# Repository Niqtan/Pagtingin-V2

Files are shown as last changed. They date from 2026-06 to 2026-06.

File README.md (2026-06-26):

# Pagtingin (Obstacle Detecting Glasses) 2.0

## Project Aims

The Pagtingin obstacle detecting glasses aims to help visually impaired people to easily detect obstacles in front of them through innovative glasses. While traditional walking sticks indeed help in detecting obstacles on the ground, they often fail to identify objects at chest or head level, such as low-hanging branches, open cabinets, or protruding signs. 

Hence, Pagtingin aims to aid this limitation and ensure a safe journey of navigation. Whether indoors or outdoors, the device will be able to identify potential hazards through a Time-of-Flight sensor and send real-time audio feedback, which helps users to be much more confident and safe in the user's day-to-day lives.

Pagtingin 2.0 uses a modular approach instead of a tightly coupled design, making the system easier to iterate on and refine over time. Some design changes and iterations also have been made.

## Zine
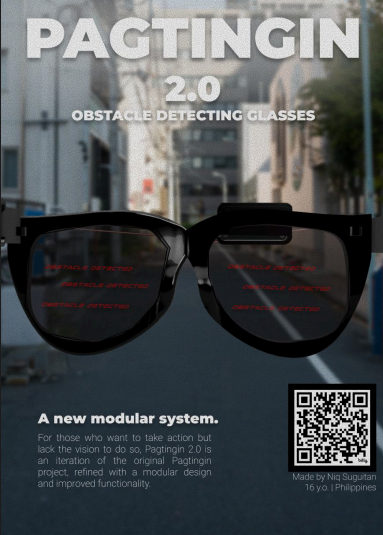
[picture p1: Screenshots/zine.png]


## Prototype Concept
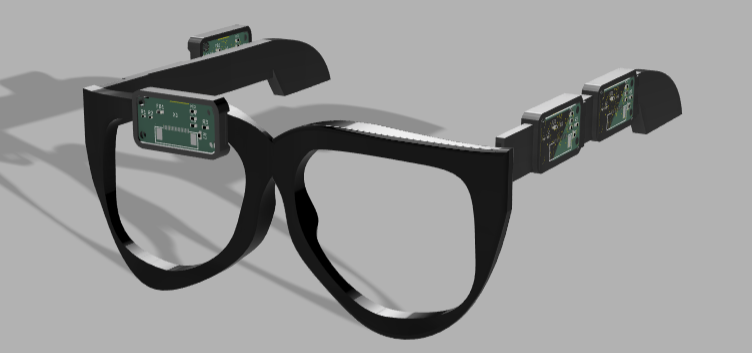
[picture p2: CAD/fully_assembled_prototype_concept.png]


## PCB 

### Main Module

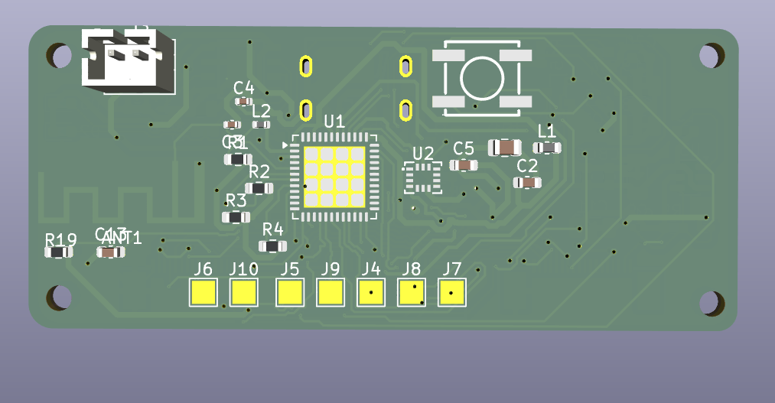
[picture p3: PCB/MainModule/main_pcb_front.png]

Image 1. Main PCB Module Front View

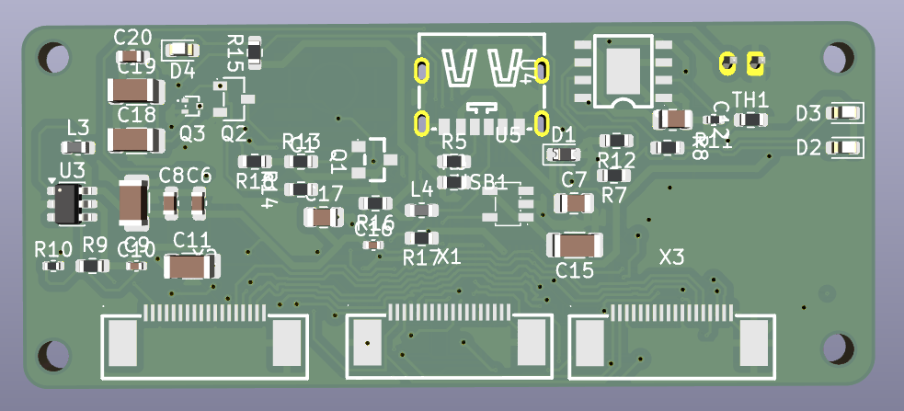
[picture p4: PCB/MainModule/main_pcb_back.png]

Image 2. Main PCB Module Backk View

### Audio Module
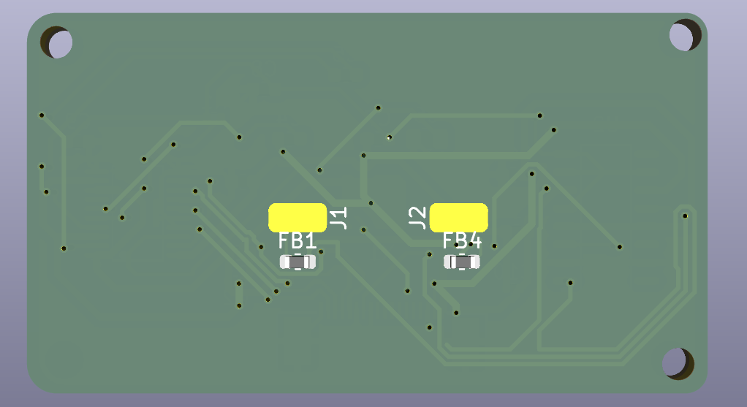
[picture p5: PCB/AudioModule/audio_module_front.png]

Image 3. Audio PCB Module Front View

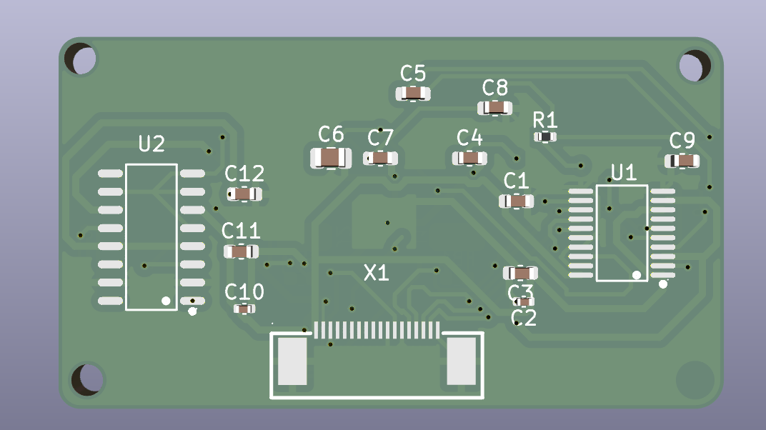
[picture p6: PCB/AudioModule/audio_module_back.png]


Image 4. Audio PCB Module Back View

### Sensor Module

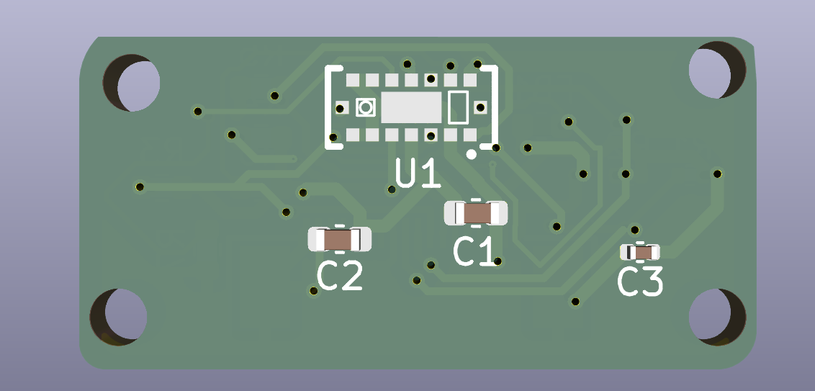
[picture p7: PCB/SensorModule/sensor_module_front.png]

Image 5. Sensor PCB Module Front View

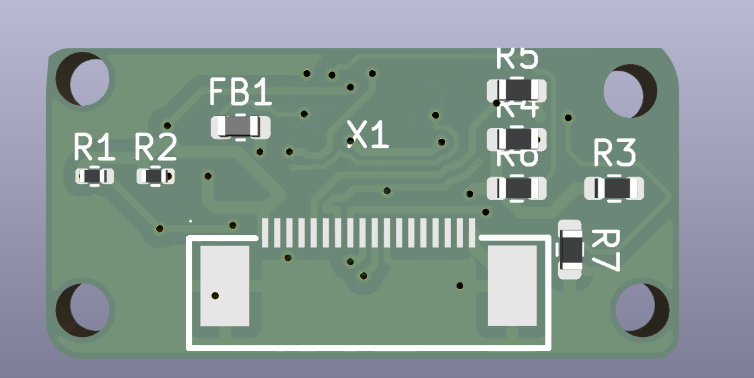
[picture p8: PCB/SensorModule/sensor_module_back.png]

Image 6. Sensor PCB Module Back View

## CAD

### Glasses Frame (with new hinges)

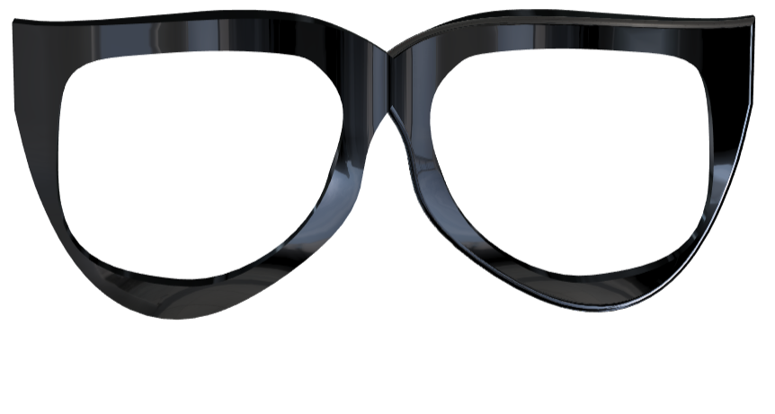
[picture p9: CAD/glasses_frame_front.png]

Image 7. Glasses Frame Front View

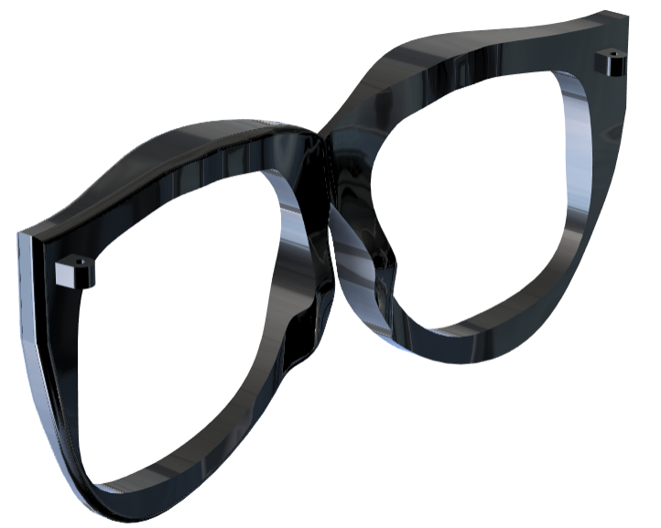
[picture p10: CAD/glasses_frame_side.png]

Image 8. Glasses Side View

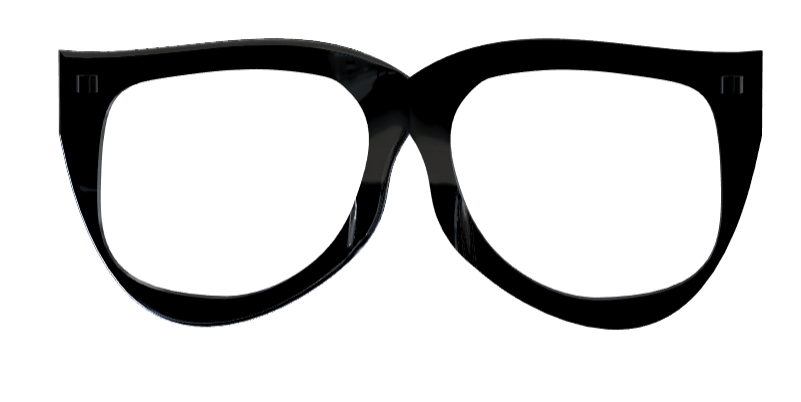
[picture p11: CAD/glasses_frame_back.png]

Image 9. Glasses Frame Back View

### Temples

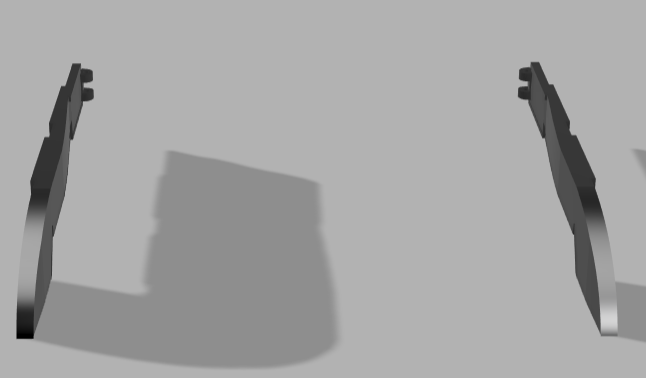
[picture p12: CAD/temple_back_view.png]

Image 10. Glasses Temple Back View

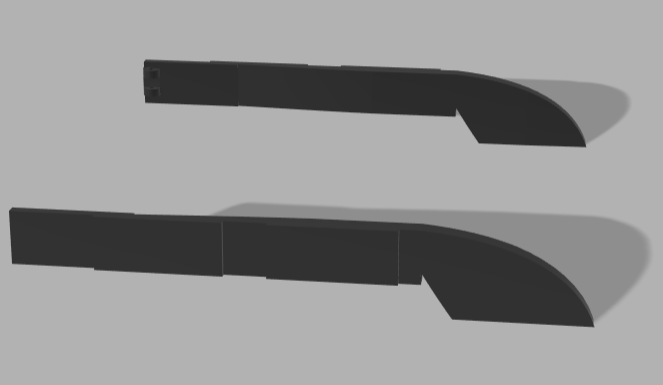
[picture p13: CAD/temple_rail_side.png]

Image 11. Glasses Rail Side View

### Module Pod
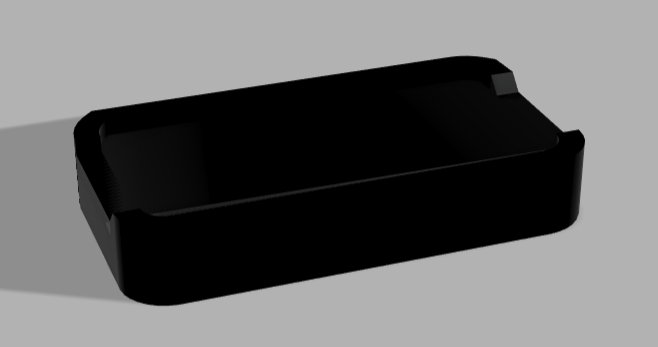
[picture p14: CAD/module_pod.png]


## 3D Printing
In terms of 3D printing, it might be better to print this in resin since the glasses frame will require precise dimensions. You may be able to print this in FDM, but it is recommended for the parameters to be as precise as possible.

## BOM

### BOM
[Bill of Materials](BOM.csv)

## Firmware
Still in progress. You may see previous prototypes in the folder for previous version's firmware. But for the firmware, I am planning to use the ESP-IDF in programming it. I chose the ESP-IDF because it allows full control over the ESP32-PICO-D4's peripherals and such. (also because I wanna challenge myself)

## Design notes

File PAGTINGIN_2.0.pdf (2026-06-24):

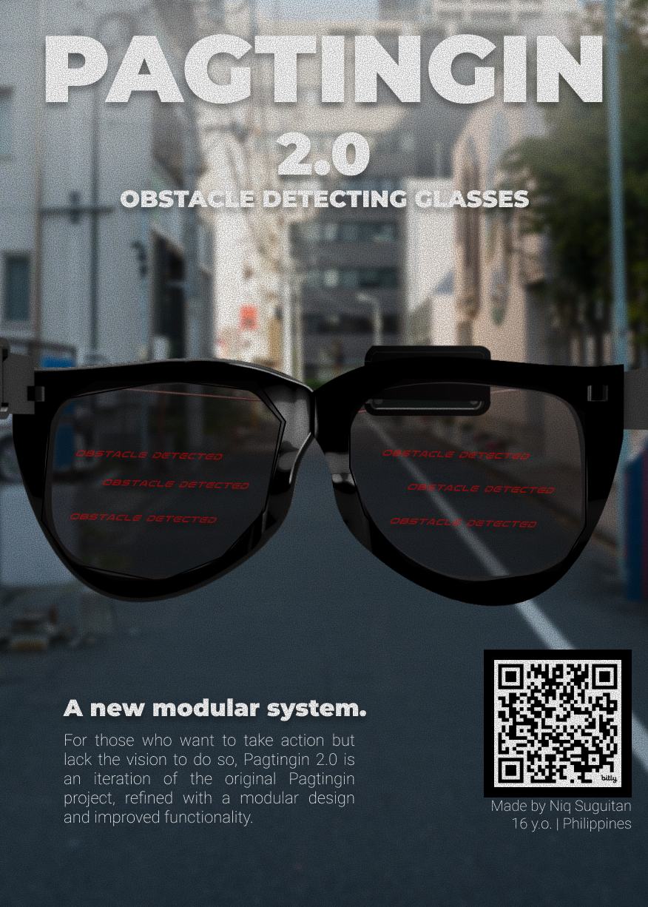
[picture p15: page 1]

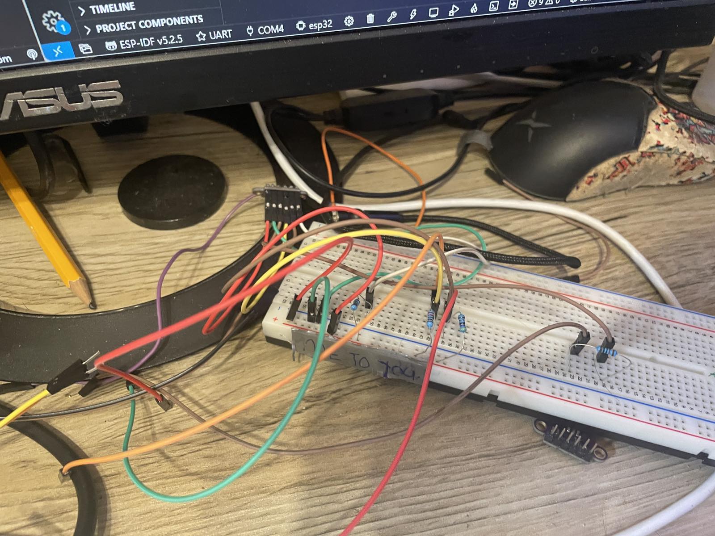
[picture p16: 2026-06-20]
Screenshots/viber_image_2025-06-27_18-02-09-457.jpg

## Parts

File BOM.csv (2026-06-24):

Comment | Quantity | Value | Footprint | LCSC Part Number | JLCPCB Component Type | Unit Price ($) | Total Price ($)
ANT1 | 1 | PCB ANTENNA 2.4GHz | RF_Antenna:Texas_SWRA117D_2.4GHz_Right |  | Extended | 0 | 0
C1,C7,C12,C17,C27 | 5 | 10µF | Capacitor_SMD:C_0805_2012Metric | C15850 | Basic | 0.0145 | 0.0725
C2,C13,C23,C31,C34 | 5 | 0.1µF | Capacitor_SMD:C_0603_1608Metric | C14663 | Basic | 0.0078 | 0.039
C3,C4,C10,C16,C24,C32,C35 | 7 | Various RF Caps (1.2p - 22p) | Capacitor_SMD:C_0402_1005Metric | C1525 | Basic | 0.0055 | 0.0385
C5,C6,C8,C22,C25,C26,C28,C29,C30,C33,C36,C37 | 12 | 1µF | Capacitor_SMD:C_0603_1608Metric | C15849 | Basic | 0.0084 | 0.1008
C9,C11,C15,C18,C19 | 5 | 22µF | Capacitor_SMD:C_1206_3216Metric | C12881 | Basic | 0.0365 | 0.1825
C20 | 1 | 4.7µF | Capacitor_SMD:C_0603_1608Metric | C19666 | Basic | 0.021 | 0.021
D1 | 1 | PTVS17VS1UR,115 | Diode_SMD:D_0603_1608Metric | C85414 | Basic | 0.046 | 0.046
D2,D4 | 2 | XL-1608PGC-06 | LED_SMD:LED_0603_1608Metric | C965863 | Basic | 0.026 | 0.052
D3 | 1 | XL-1608VRC-06 | LED_SMD:LED_0603_1608Metric | C84256 | Basic | 0.0195 | 0.0195
FB1,FB4,FB5 | 3 | MAF1608FAD151CT000 | Inductor_SMD:L_0603_1608Metric | C1033 | Basic | 0.0135 | 0.0405
J1,J2 | 2 | ESP-PROG Headers | Custom Pin Headers | C124313 | Extended | 0.115 | 0.23
J3 | 1 | USE-702528-500PCBJST | Connector_JST:JST_PH_B2B-PH-K_1x02_P2.00mm_Vertical | C131337 | Extended | 0.255 | 0.255
J4 to J12 | 9 | TestPoint / Wire Pads | TestPoint:TestPoint_Pad_2.0x2.0mm |  | Basic | 0 | 0
L1,L3,L4 | 3 | Power Inductors (2.2µ - 10µ) | Inductor_SMD:L_0603_1608Metric | C168316 | Basic | 0.068 | 0.204
L2 | 1 | 1.8nH | Inductor_SMD:L_0402_1005Metric | C148419 | Basic | 0.026 | 0.026
Q1 | 1 | AO3401A | SOT-23 | C15127 | Basic | 0.045 | 0.045
Q2 | 1 | MMBT2907ALT1G | SOT-23-3 | C40752 | Basic | 0.032 | 0.032
Q3 | 1 | MMBT2222AM3T5G | SOT-723-3 | C896289 | Basic | 0.035 | 0.035
R1,R2,R3,R4,R12,R19,R26 | 7 | 10kΩ | Resistor_SMD:R_0603_1608Metric | C25804 | Basic | 0.0032 | 0.0224
R5,R6 | 2 | 56KΩ | Resistor_SMD:R_0603_1608Metric | C23204 | Basic | 0.0032 | 0.0064
R7,R8,R20 | 3 | 1kΩ | Resistor_SMD:R_0603_1608Metric | C21190 | Basic | 0.0032 | 0.0096
R9,R28,R29,R30,R31 | 5 | 47kΩ | Resistor_SMD:R_0603_1608Metric | C25741 | Basic | 0.0032 | 0.016
R10 | 1 | 4k7Ω | Resistor_SMD:R_0402_1005Metric | C25900 | Basic | 0.0038 | 0.0038
R11,R27,R32 | 3 | 2kΩ / 2k2Ω | Resistor_SMD:R_0402_1005Metric | C25890 | Basic | 0.0038 | 0.0114
R13,R14,R18 | 3 | 10KΩ | Resistor_SMD:R_0603_1608Metric | C25804 | Basic | 0.0032 | 0.0096
R15 | 1 | 100kΩ | Resistor_SMD:R_0603_1608Metric | C25814 | Basic | 0.0032 | 0.0032
R16 | 1 | 360kΩ | Resistor_SMD:R_0603_1608Metric | C120761 | Basic | 0.0042 | 0.0042
R17 | 1 | 80.6kΩ | Resistor_SMD:R_0603_1608Metric | C121287 | Basic | 0.0042 | 0.0042
SW1 | 1 | KSC441JST2LFS | KEY-SMD_4P | C221750 | Basic | 0.213 | 0.213
TH1 | 1 | NCU18XH103F6SRB | Resistor_SMD:R_0603_1608Metric | C162670 | Basic | 0.075 | 0.075
U1 | 1 | ESP32-PICO-D4 | QFN-48-1EP_7x7mm_P0.5mm | C193707 | Extended | 4.1816 | 4.1816
U2 | 1 | BMI270 | LGA-14_L3.0-W2.5-P0.50 | C2836813 | Extended | 4.1911 | 4.1911
U3 | 1 | TLV61070ADBV | Package_TO_SOT_SMD:SOT-23-6 | C6881375 | Basic | 0.284 | 0.284
U4 | 1 | TP4056 | ESOP-8 | C16581 | Basic | 0.114 | 0.114
U5 | 1 | RT8059GJ5 | SOT-23-5 | C20542 | Basic | 0.142 | 0.142
U6 | 1 | PCM5102 | TSSOP-20_L6.5-W4.4-P0.65-LS6.4-BL | C107671 | Extended | 1.98 | 1.98
U7 | 1 | PAM8403DR | SOP-16 | C5122557 | Extended | 0.221 | 0.221
U8 | 1 | VL53L5CXV0GC_1 | LGA-16 | C3178303 | Extended | 7.4367 | 7.4367
USB1 | 1 | TYPE-C 6P | TYPE-C-SMD_TYPE-C-6P_1 | C456012 | Basic | 0.091 | 0.091
X1,X2,X3,X4,X5 | 5 | AFC07-S18FCA-00 | FPC-SMD_AFC07-S18FCA-00 | C262564 | Extended | 0.162 | 0.81
Total |  |  |  |  |  |  | 21.2695

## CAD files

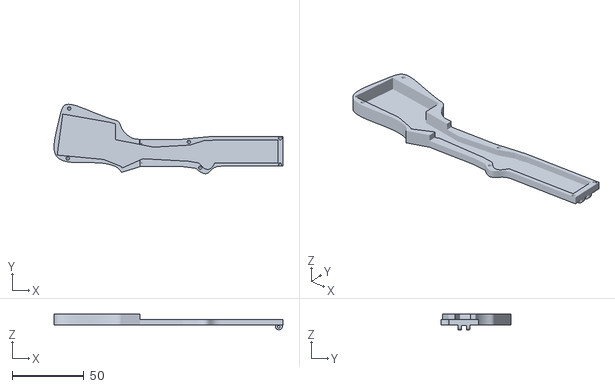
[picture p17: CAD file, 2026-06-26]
CAD/Temples Hinges.stl
159.5 x 48.4 x 10.8

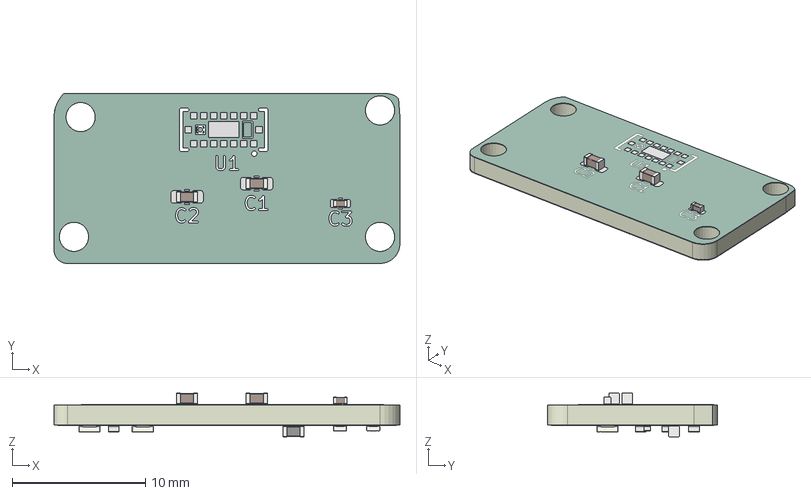
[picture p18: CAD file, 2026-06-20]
PCB/SensorModule/sensor_module.step
26.0 x 12.8 x 3.28 mm
C_0603_1608Metric x 2
C_0402_1005Metric
L_0603_1608Metric
R_0603_1608Metric x 5
R_0402_1005Metric x 2
Pagtingin_V2_Sensor_copper
Pagtingin_V2_Sensor_pad
Pagtingin_V2_Sensor_via
Pagtingin_V2_Sensor_silkscreen x 2
Pagtingin_V2_Sensor_soldermask x 2
Pagtingin_V2_Sensor_PCB

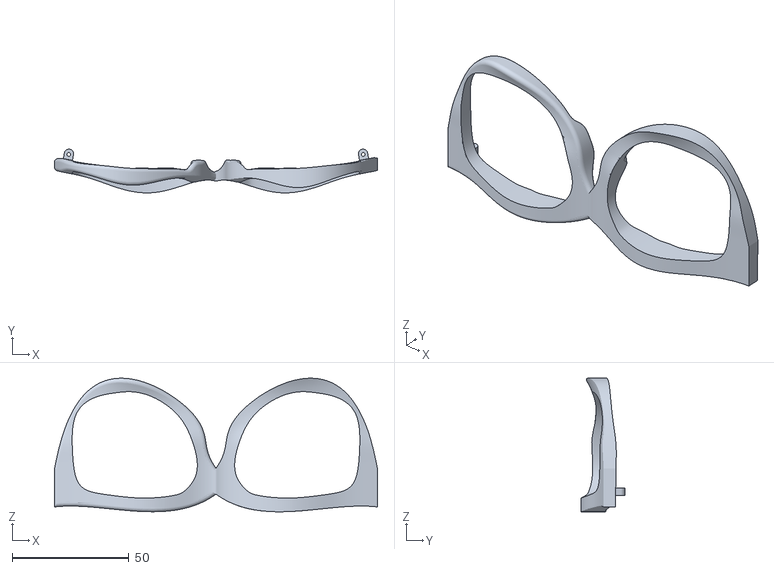
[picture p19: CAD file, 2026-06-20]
CAD/Glasses_Frame_With_Hinges.stl
138.6 x 18.8 x 57.3

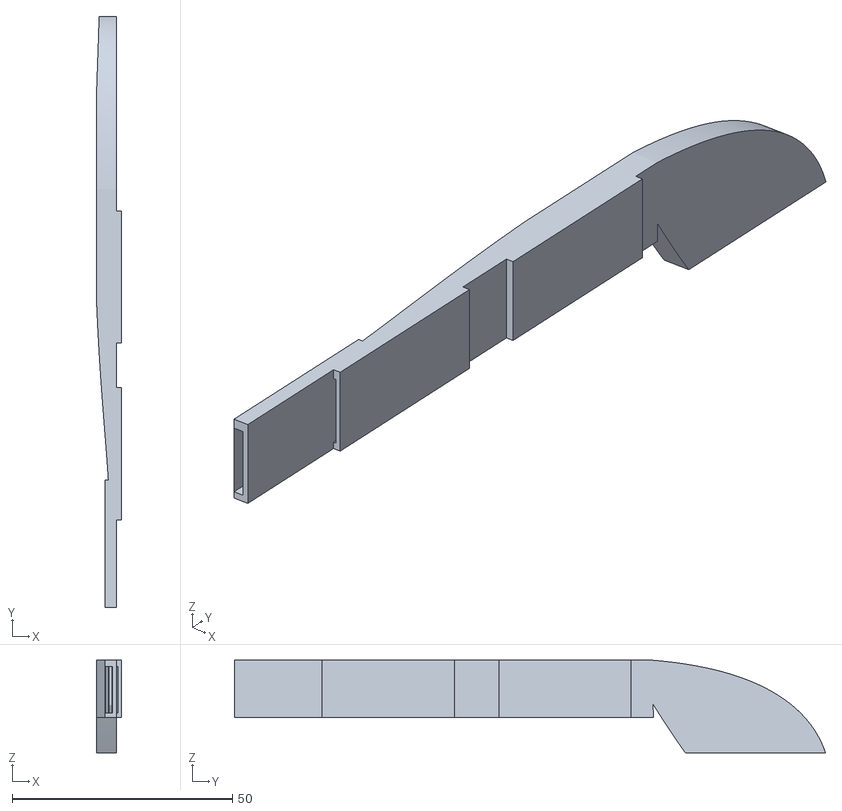
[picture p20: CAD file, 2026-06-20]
CAD/Left Temple.stl
5.70 x 134.1 x 21.0

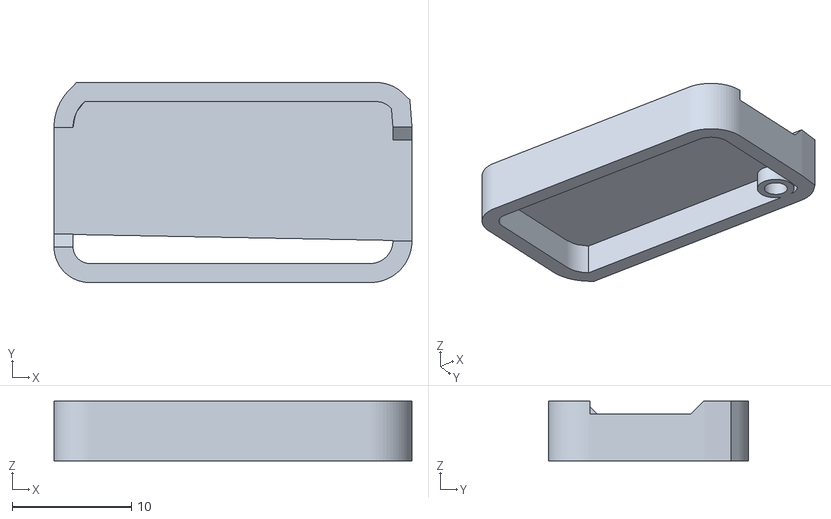
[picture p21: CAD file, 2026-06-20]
CAD/Pod.stl
30.0 x 16.8 x 5.00

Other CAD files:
CAD/Right Temple.stl
CAD/Glasses_Temples_with_hinges.f3z
CAD/Sensor_Module_Pod.f3d

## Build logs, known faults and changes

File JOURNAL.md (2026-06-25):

---
title: "Pagtingin V2"
author: "Niq Suguitan"
description: "A vision without action is called a daydream; but then again, action without a vision is called a nightmare."
created_at: "2026-05-21"
---

| Date started: May 21, 2026

# Pagtingin V2
Okay. I think it is time to start working on this project again. It's been literally almost a year since I've touched this project and all I can say is that I've changed a lot in those years. Now, we're back in Summer 2026 to work on this.

I guess to start, I would like myself to check up on why I gave up on this in the first place
- Clearly, it failed because I switched the positions of the pins of the MCU. So technically, I was quite literally trying to make it work but I had swapped the footprint pins to connect to different signals that weren't actuallly  the right footprint pins in thea actual footprint. Okay, so to explain on it much simpler, I switched each pins of the footprints to make routing easier. however, in the adctual footprint, no pins are switched, making the signals i've connected not corresponding to the actual footprint.

So that is definitely one problem, I would say.

Here's the complete list of problems that I noticed while making the PCB

1. Both PCBs were INCREDIBLY messy as hell. There were so many wires going through each of them, and it just didnt look good.
2. How the hell do you even program an ESP chip? This were mainly one of the main reasons why everything became messy
3. Some things weren't available when I asked JLCPCB to  solder all of the parts in the PCB. Also yeah, my soldering was js plain messy
4. Didn't account for some measurement of the 3d print
5. 3d printed glasses' hinges didn't work
6. And of course, the ESP32's footprint layout was wrong.

Clearly, there were so many problems here because I was so rushed into making this for Highway. But worry not, I'll try to fix them this summer.

## First Problem: How to program the ESP32-PICO-D4
I guess the first thing I can start working on is how would you even try programming the ESP32-PICO-D4 if its just a sole chip?

To program it you would need to use a USB-TO-UART bridge and programming it via the Arduino IDE.

I guess also one of the main reasons why we couldnt program the ESP32-PICO-D4 was that the pogo pins didn't fit the holes.
- This was also to me messing with the footprint's sizes.

So apparently the ESP32-PICO-D4 uses a UART bootloader mode in which it allows for firmware to be flashed over the serial communication protocol, UART.
- For this project, I think we can keep the FT2232HL-Based flashing

## Second Problem: How to know if the power delivery is working?
We test with the current version and see with a multimeter tester if the power delivery is indeed working as intended.

## Third problem: 3D Printed Hinges
The temples were okay and the PCB was able to fit but the problem was that the hinges didn't quite connect with each other.

We would probably need to add little tweaks to the 3D print and most likely try to see if it shall work.

I'll research on the META glasses how did they fit PCBs in their frames.

Going through the teardown of the meta rayban glasses, I noticed that they use a lot of flex PCBs. Flex PCBs, frankly, are quite a foreign term for me.
But as I understand, they are more of like

Quick notes:
- All the frames and the arms are made of plastic (NOT 3D PRINTED)
- Flex PCBs are more of used to houses the sensors such as proximity and light

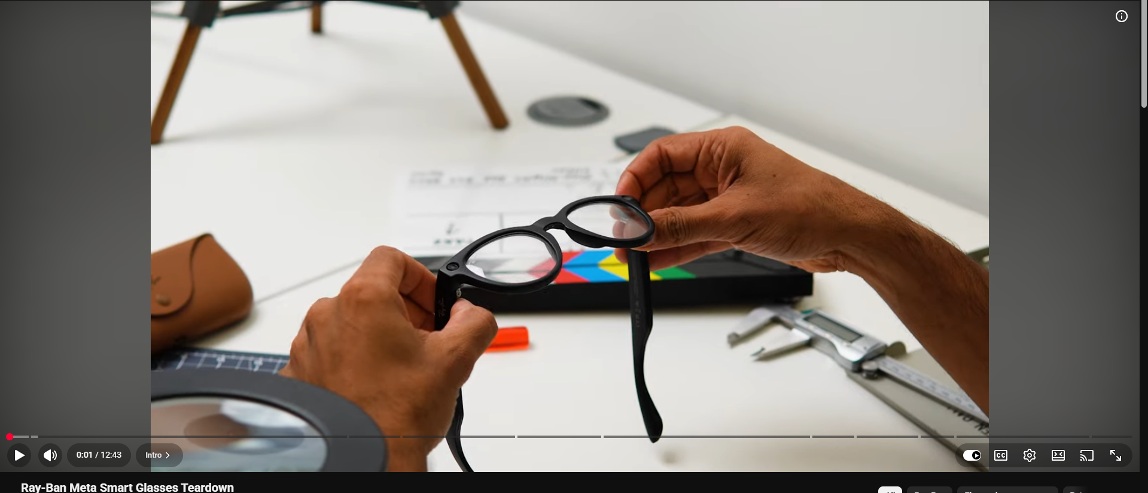
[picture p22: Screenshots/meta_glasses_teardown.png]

So clearly, that teardown had my head not working anymore. I feel so overwhelemd redesigning all of this, so I think here are a couple of suggestions to make this project much less complex.

1. Use a ESP32 Module instead of the chip
2. Use templates from websites such us thingiverse and merge them with my current design
3. Sanity check from people

# Entry 01 - 05-27-26 - Starting with reducing the complexity of the project

Okay, ever since I've found out how complex this project was, I've always kept pushing that all will be fine and that I'd be able to get this done easily.

However, I don't think I can do that anymore. It's finally time.

Here were some problems things that I thought would be increasing the complexity of my project:
1. The microcontroller as a chip
2. FFC connectors 

First let's solve the problem of the microcontroller being a chip
- Honestly, trading it for the size, I just dont think I'll be replacing the chip for a devboard or whatever

FFC and FPC connectors
- I think it would be better if I got flex pcbs so that it can travel within the temple, frame, and temple pretty easily.

Studying the meta glasses teardown, apparently the way the two temples are connected to each other is this order:
Any temple -> hinge -> front frame PCB (in between in the lenses)

And then basically the front frame PCB connects both temple's pcb
- I have no idea how I am going to ever reach that level of making a pcb

For meta glasses the way they do is that:
- Two halves of a temple are glued together

According to GPT, the best way to connect the two boards is to use a Flex PCB.
Another very bad problem is that the 3d print isnt hollow.

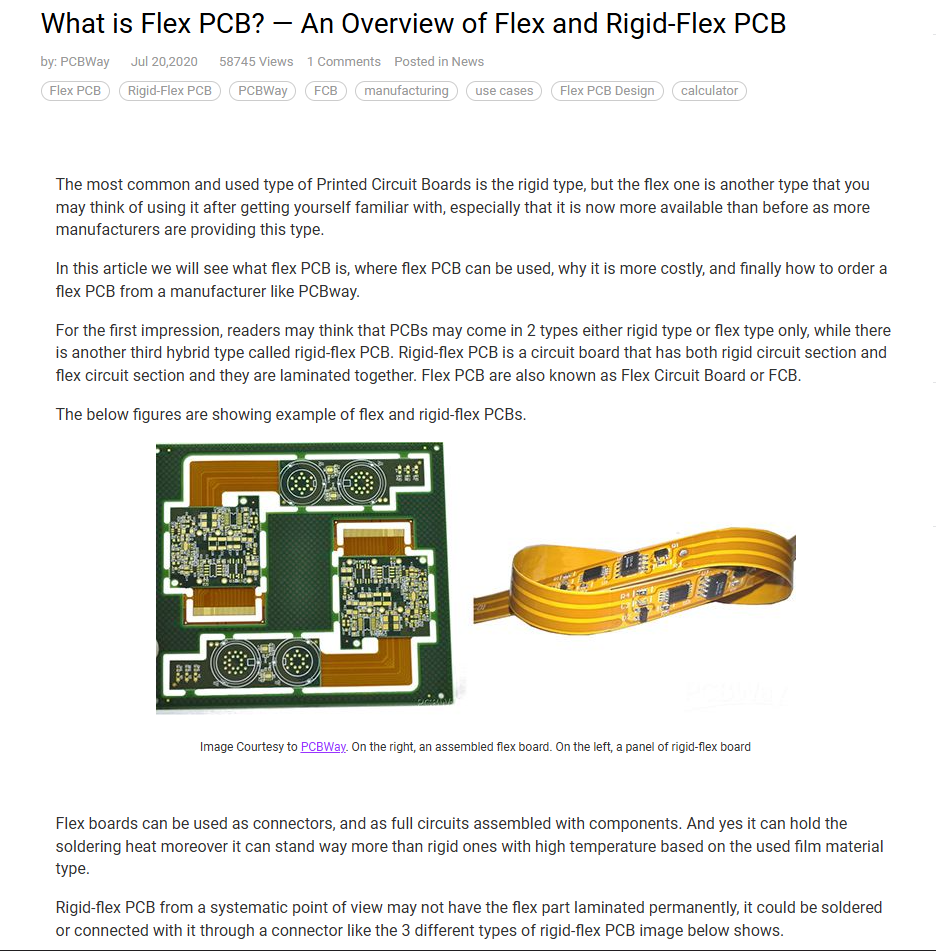
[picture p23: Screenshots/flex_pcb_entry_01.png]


Also for today, I tried to restore my files.

Anyways for the next journal, I plan to change up the 3D  Model. I think the PCB couldve been way better if I changed up that.

# Entry 02 - 05-29-26 - Changing up the structure of Pagtingin

I am  revisiting back my 3D models for the Pagtingin. And yeah, honestly making all of it connect like the Meta Glasses will be hard because

Internal wiring is super complicated. I've tried that out in version 1 and I underestimated how complex it can be.

Hence, I thought of a new idea. What if we truly made it so modular? What if, like earbuds, we have different electronic pods around the glasses and each of those pods would have different modules with different functionality?

Introducing...

Pagtingin V2! (Picture made by CHATGPT)

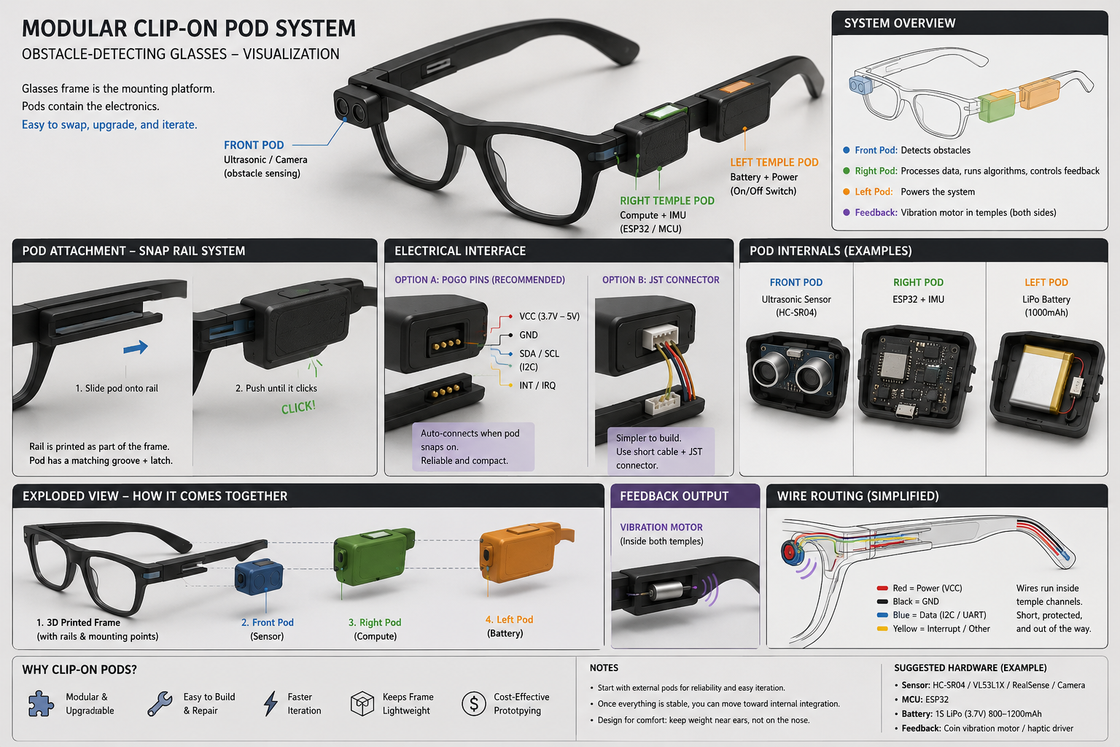
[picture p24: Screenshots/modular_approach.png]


Okay so I believe this type of modular approach would not only reduce the complexity but also help a lot in debugging as it separates itself now in 3 zones.

So yeah! Let's start with revising the schematic first by making them into different PCBs.

So we'll be primarily separating the glasses into three parts:
1. The Main Board module
- This includes the brain (MCU)
- The main logic (audio and stuff)
- Also main regulation happens here

2. The Power System 
- This includes the battery itself and the power modules
- Includes: battery, charger, regulations, and protetions

3. Sensing module
- Includes the input 
- Facing front of the glasses

4. Audio module
- Includes the output modules 

What's next is to sanity check first the electrical connections and then lets make that PCB for the electronic pods!

Let's make this a cool ass project frfr

Oh yeah apparently, I also have to decide on a system bus. It's basically how will each module communicate and transfer power. For communication, I'd use:

Main Communication protocol
I2C 

Power rails
And for power rails, I think I'd rather keep the current power rails right now. Maybe I'll modify them depending on it.

And control / utility lanes
- RESET BUTTON
- INT
- EN 
(Would connect these to the power system)

# Entry 03 - 05-30-26 - More ideas + revising the schematic

So I went on consulting with a friend about my glasses. He suggested that I use a power bank cable to represent the PCB. Then it would come from your pocket, routing to your glasses.

I believe this one is quite intriguing because it opens up to the fact that its ergonomically better. Less weight and all.

However, I still wanna go for the modular approach.

Oh yah, for the main board here are some things I need to think of:
1. How am I supposed to connect the modules together with the ESP32-PICO-D4 chip?
- Perhaps I can use soem sort of things to breakout these pins?

2. How am I supposed to program this? Perhaps its Pogo pins are exposed for me to program it with my current EPS32-PROG
- Same situation with this

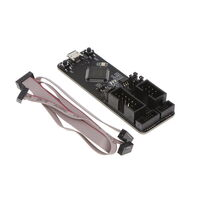
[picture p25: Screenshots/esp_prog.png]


Also apparently you can pre-program chips so that's definitely interesting.
- You can use a pogo-pin jig to program them so u dont have to put headers anymore
- To do this you will need to expose the copper pads of those pins
- This is the one i picked
- Now it's only a matter of having a pogo pin jig
And then you can also pre-program them by using a chip socket programmer   
- Only do this if you're confident that your firmware will work

In terms of the other pins, I have decided to use JST connectors so that it can make permanent connection
- The cables will be inside the glasses frame, routing using the system bus to other modules in the system

I decided to go with using FFC connectors so I can connect the modules with each other.

There's like nuance here that I have to keep in mind and its that I should be using a system bus with the fixed amount of pins
- That basically means that I will be placing let's say a FFC connector with a fixed number of pins. The same pins should be used as a FFC connector to the other modules but each nodule ONLY takes what it needs

For example:

Each module will have a 14 pin FFC connector. Even if a module doesnt need one of those signals, it will still have the same amount of pins. However, the signals it doesn't need will be NOT CONNECTED (NC)

Anyways, I will be checking each hierarchical schematic and see what signals do each module need. And then, we can decide on how many pins the FFC Connector should have.

Also just a reminder to take a look at LCSC so that we know what is in stock and if JLCPCB can do PCB assembly with that.

# Entry 04 - 06-02-26 - Implementing the FFC Connectors

So here are the signals we primarily need that need to be universal with all modules:

3.3V
5V
GND (Power)
SDA (IO 21, For TOF Sensor)
SCL (IO 22 For TOF Sensor)
GND(Sensor)
I2S_LRCK (IO32 for the PCM5102)
I2S_DIN (IO33 for the PCM5102)
I2S_BCK (IO27 for the PCM5102)
I2S_SCK (IO26 for the PCM5102)
I2S_XSMT (IO25 for the PCM5102)
GND (Digital)
SHND (IO23 for the PAM8403DR0)
GND(Shield)
LPN (IO18 for the TOF sensor)
INT (IO19 for the TOF sensor)
I2C_RST (IO4 for the TOF sensor)
GND(Another shield)

Hence, we need a FFC connector with at least 18 pins. I think that's the safest.

Also, while listing down the pins I needed, something came to mind:
"Is one Time of Flight sensor really fine?" I've been meaning to answer this question. There are pros and cons if I do only have one and two.

One TOF Sensor:
- Less coverage for the vision
- In a sense "tunnel vision"

Two TOF Sensors:
- More coverage
- More complexity

One TOF sensor & 1 IMU
- Best out of all the options
- The TOF sensor detects an obstalce in front while the IMU refines that result into something much more specific
- Basically the IMU gives the context of the situation while the TOF sensor sees

So yeah it'll definitely be helpful if I had an IMU sensor giving context to the entire system of what's happening.

Okay another thing would be:
- Do we separate the things off the main board? Yes and no. What's better is that we separate the distance sensors from the main board so that we may make it more modular, and then we put the IMU sensor and  main board together so that they can both working together to produce data that the entire system needs.

Okay here's the revised architecture:
🧠 Main module (processing + power processing)
🎧 Audio module left
🎧 Audio module right
📡 Sensor module(s)

Here's an AI created image. Apologies if I make these with AI, but I believe it is faster to prototype if that's the case:
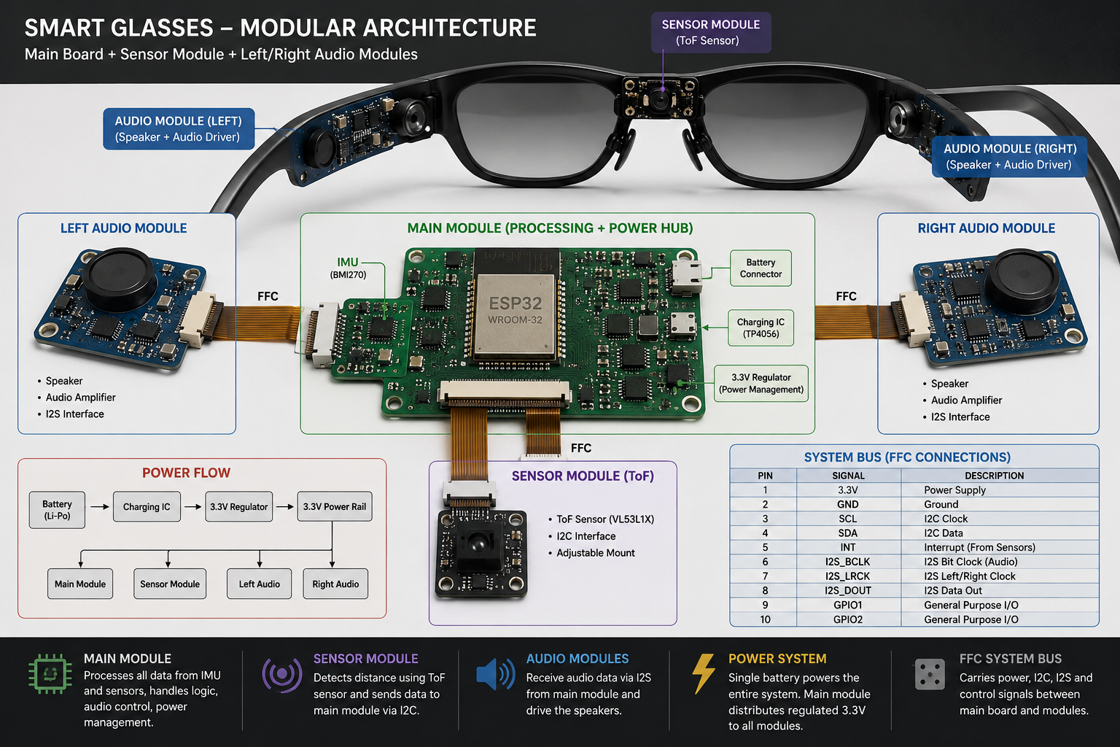
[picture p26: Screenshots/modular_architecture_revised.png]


With that, I put 3 FFC connectors with 16 pins each on the main board.
- I js gotta worry about the vertical clearance

Next time im gonna pick out the best FFC connector.

# Entry 05 - 06-05-26 - Implementing the FFC Connectors (fr this time)

Okay! so I've finally implemented the FFC connectors. Just thinking whether or not we should use 3 FFC Connectors for this.

So introducing the AFC07-S18FCA-00:

It is a 18 pinned FFC connector with a pitch of 0.5mm. It's a pretty standard FFC connector and I believe it'll be able to fit inside the glasses.

Also I recently started using this new tool called easyeda2kicad. This helps with my workflow  ALOT. Like genuinely, I don't have to keep converting the files I see on easyeda to kicad with a web browser. It just does it on my terminal.

Okay, so I've successfully integrated the FFC connectors to the different modules.

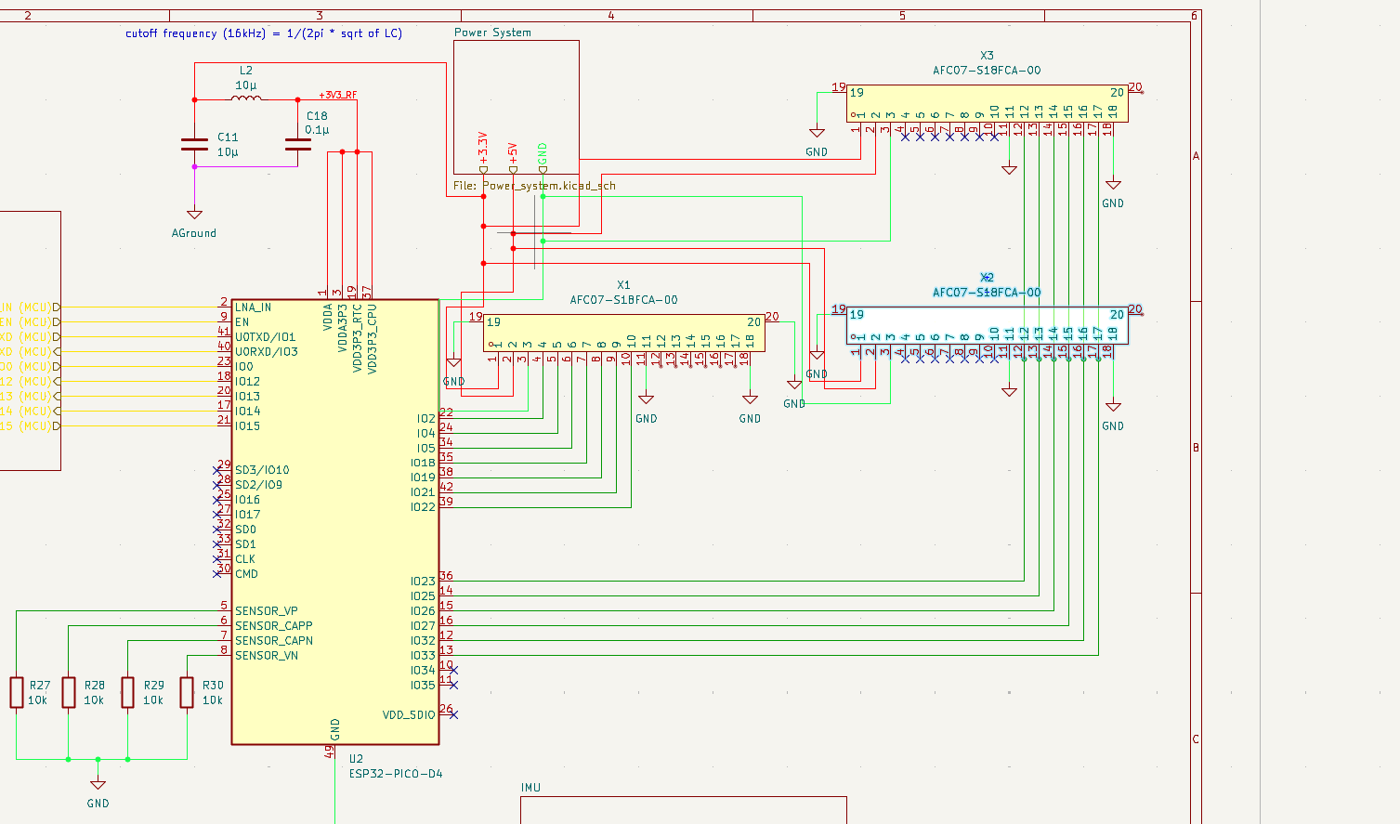
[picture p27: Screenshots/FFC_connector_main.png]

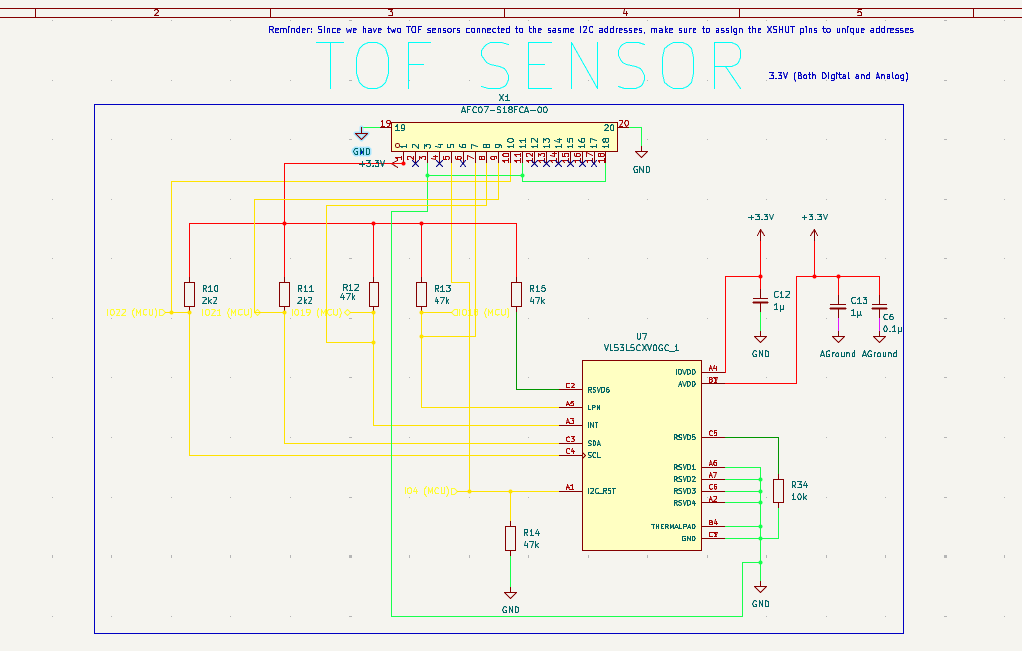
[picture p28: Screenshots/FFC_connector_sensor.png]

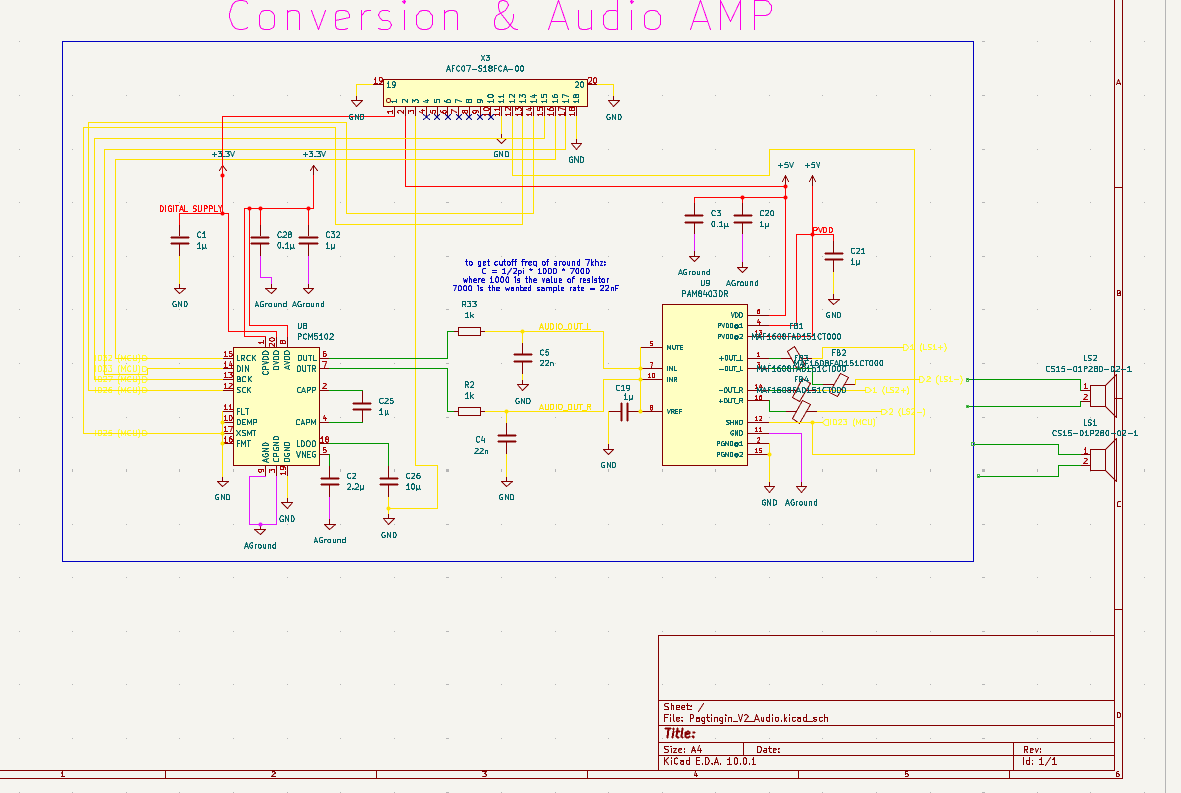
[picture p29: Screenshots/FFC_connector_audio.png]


For the next session, I wanna try probing on the different electrical connections in the PCB from the version 1 of the project. I wanna see if the power system I created in version 1 works with the current system.

# Entry 06 - 06-06-26 - Connecting the IMU to the MCU

Okay so I'm just gonna do a small thing today and its connecting the IMU to the respective pins of the MCU.

Yep. After following the datasheet, here is what I ended up with:

Also learned that some things can be left unconnected depending on their purpose in the overall system. So for this BMI270, I left u unconnected ASC, ASD, OCSB, and OSDO because they were all used for auxilliary connections. And yeah, by name, "auxilliary" basically means support or extra features in this case.

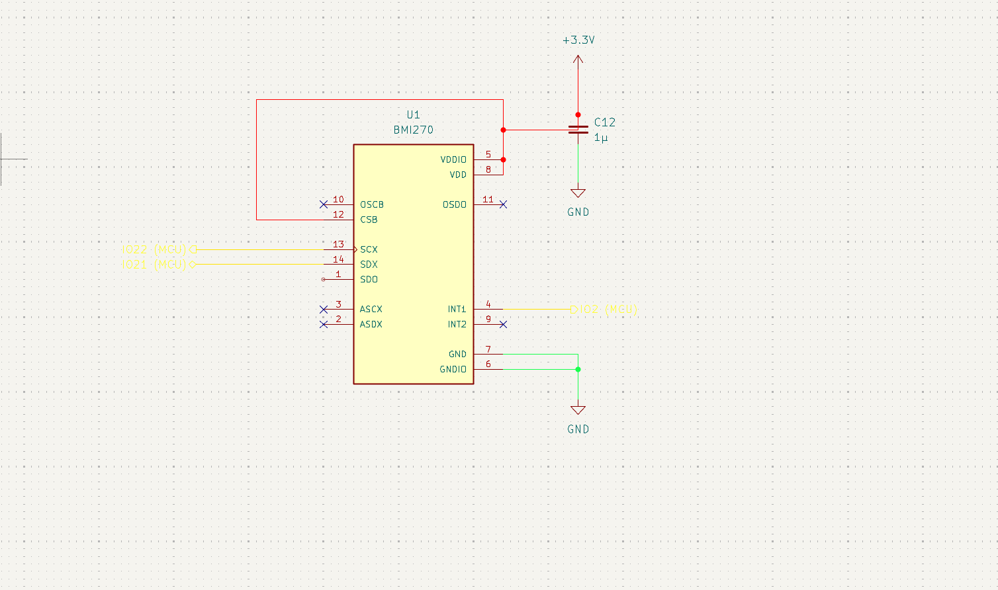
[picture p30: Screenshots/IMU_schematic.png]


# Entry 07 - 06-10-26 - Back to revising the power system

Okay so what I'm generally concerned for is my latching circuit. I'm not so sure if it works, even when I transferred it over to a new board.

See the image below:

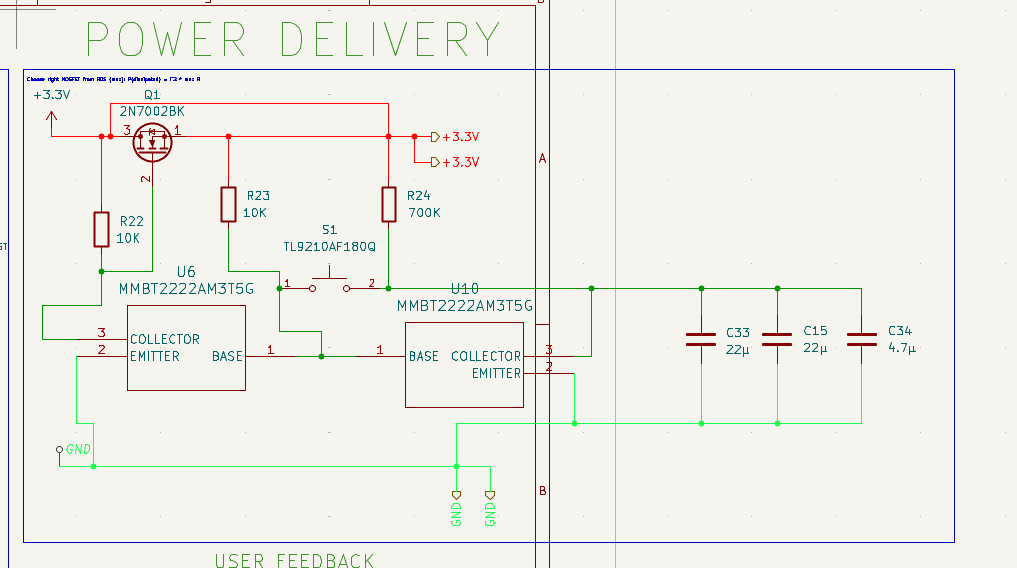
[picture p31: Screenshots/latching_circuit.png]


Okay, so according to chatgpt, I asked the AI to do a sanity check of my latching circuit.

To understand latching circuits, is to also core to understand feedback loops.
- The core idea of a feedback loop is that the latching output is fed back in the input in order to keep itself alive (the system)

The building blocks of a latching circuits are:
- NOR or NAND gates
- The SR latch is the simplest digital latch; it has two inputs which are SET (sets the output on) and Reset (sets the output off) 

It basically said that I used the wrong type of MOSFET, an N-channel MOSFET, instead of a P-channel MOSFET.

Just to explain it, an N-channel MOSFET is basically used for high-side switching.

Here's an article detailing latching relay:
https://www.instructables.com/The-Most-Efficient-Latching-Circuit/  

So what is a relay?
- Its an electromagnet controlling a switch

That concludes some learning for today. my brain's ultimately fried

# Entry 08 - 06-11-26 - Revising the power system v2

Okay so I wanna implement the knowledge above to revise my power system.

In my latching circuit, I'm going to replace the the 2N7002BK transistor because its not the right type of transistor that I need.

To do this we must first understand what is high-side switching and low-side switching
- High-side switching is when the switch is placed between the power source and the load itself
    - When the switch is closed, power flows into the load. When the switch is open, the connection to the power supply is cut off completely.
- Low-side switching is when the switch is placed between the load and the ground
    - The load is always physically connected to the power supply. The switch acts as a gatekeeper to the ground. When you close the switch, it completes the path to ground, allowing current to flow.

And to get deeper into electronics and all of that, a MOSFET is basically a voltage-controlled valve
- Gate (the lever)
- Drain (Water coming in)
- Source (water going out)

So the way this works is that the gate gets a little bit of voltage. That mere presence of voltage creates an electric field that pulls the valve open.

Also I needed to replace the NPM1100-CAAA-R7. Reason being, in version 1, it was so hard trying to hot plate such small component. Hence, I'm going to use a different IC now which does a similar functionality to replace that so that it makes assembling the main module a bit easier. 

I'm going to replace it with a new charging module now. Plus maybe an LDO.

I'll do that tomorrow 

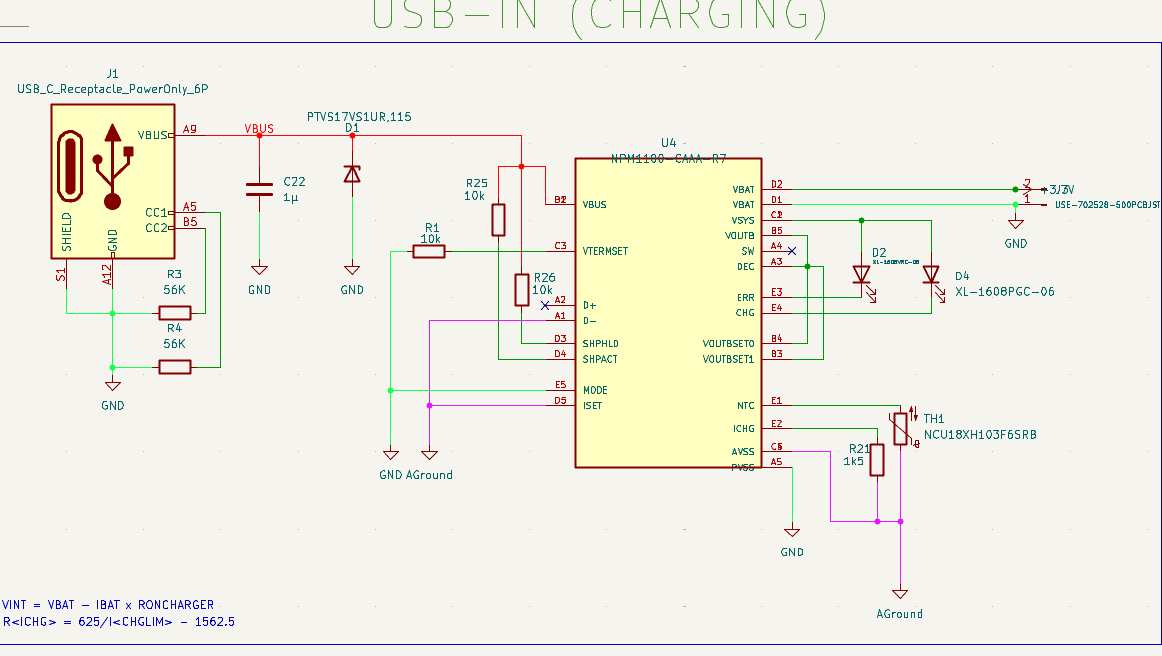
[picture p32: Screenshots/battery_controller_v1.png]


# Entry 09 - 06-12-26 - Revising the power system v3

So to replace the NPM1100-CAAA-R7, let's go try finding a similar IC like it.

So I found out about TP5400 and TP4056

The key difference  between the two modules 
- TP4056 simply takes in a 5V and safely charges the 3.7V
- TP5400 can do both charging and do a boost regulator

For this situation, having the TP4056 would be much more convenient. And then we pick a LDO.

For an LDO we must first understand these terms:
- Dropout voltage which basically is the minimum voltage that the LDO needs between the input and output to keep the output steady
- Ground current is the electrical "tax" that the LDO charges just to stay powered on and working

The LDO I picked was the XC6206P332MR
- The reason being is that it fits the specs I need in an LDO. It dropouts to 3.3V and gets current at 200mA at most.
(I just realized that I didn't need an LDO cuz i already had a buck converter lamo)

Calculating for the PROG pin of the TP4056:
RPROG = 1200/0.6

RPROG = 2000 Ohms

Some sources:
- https://www.allaboutcircuits.com/technical-articles/choosing-the-right-ldo-beyond-the-basic-specs/

Here's the revised schematic of the USB-C part of the power system:

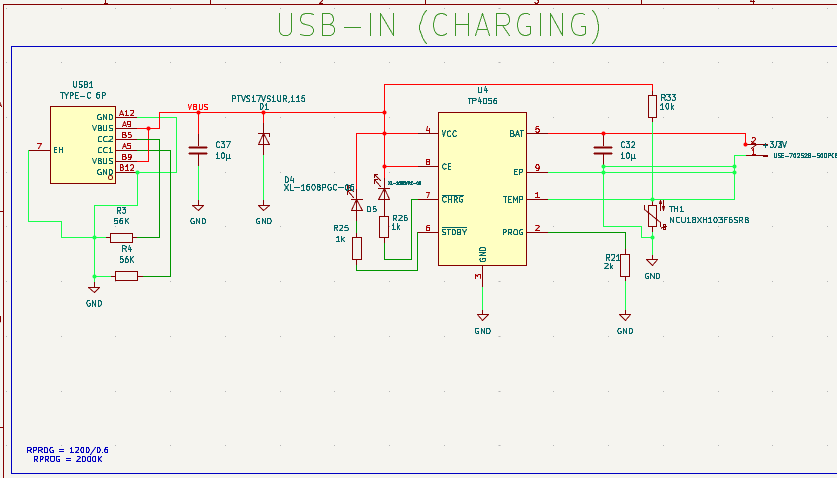
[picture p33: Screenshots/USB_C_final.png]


Okay next is I had AI sanity check my boost converter and buck converter to see if they were truly doing what I wanted them to do.

So apparently my boost converter had some problems with values:
- R9's value 47K -> 36K 
- Only having one capacitor on the output capacitance bank

For my buck converter:
This part was really well done. Just to polish it I just had to replace some values:
- C16's value is now 22pf
- R16's value is now 360k 
- R17's value is now 80.6K

Everything should be good now!
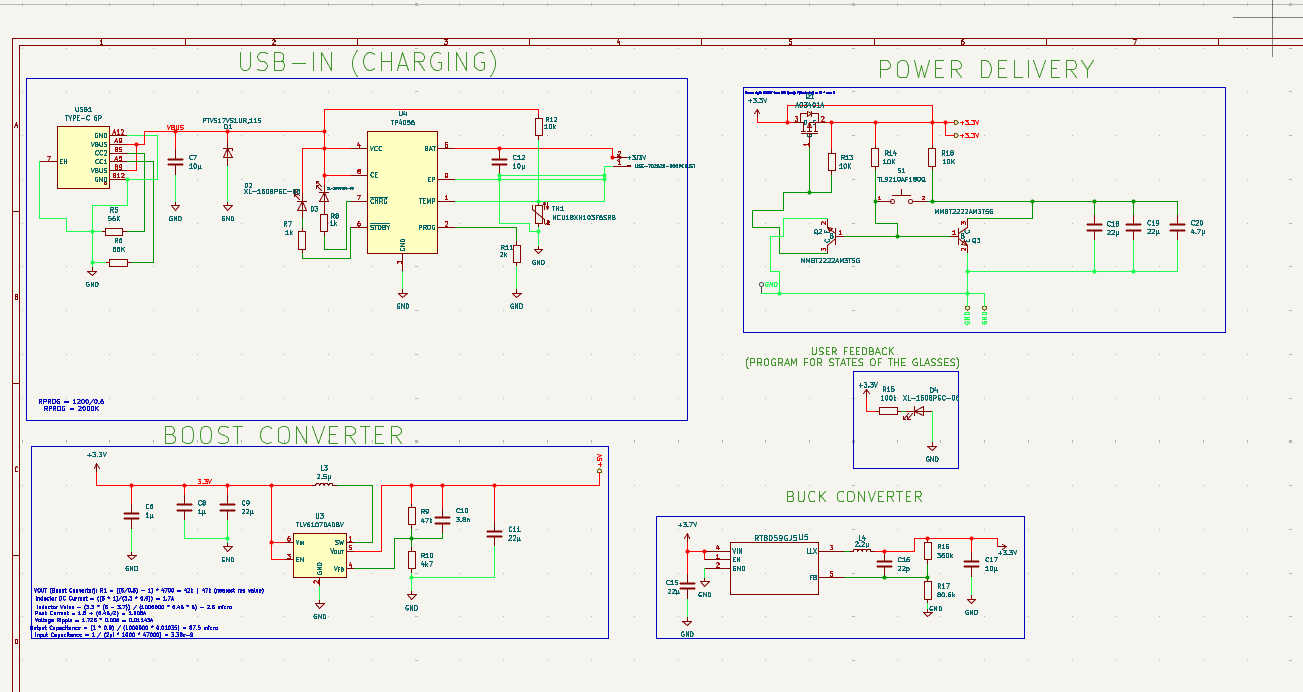
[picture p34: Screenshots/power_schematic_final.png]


# Entry 10 - 06-16-26 - Revising the audio schematic

Okay so now I've also noticed another problem with what happened with version one.

The speakers I bought weren't exactly THT that's why we couldnt really solder them onto the board. Well now, let's find for speakers.

Of course, as always, the benchmark would always be the meta glasses. I am really fascinated by this technology.

Found this little document by digikey:

https://mm.digikey.com/Volume0/opasdata/d220001/medias/docus/7182/CE%20Speaker%20Assembly%20Overview.pdf

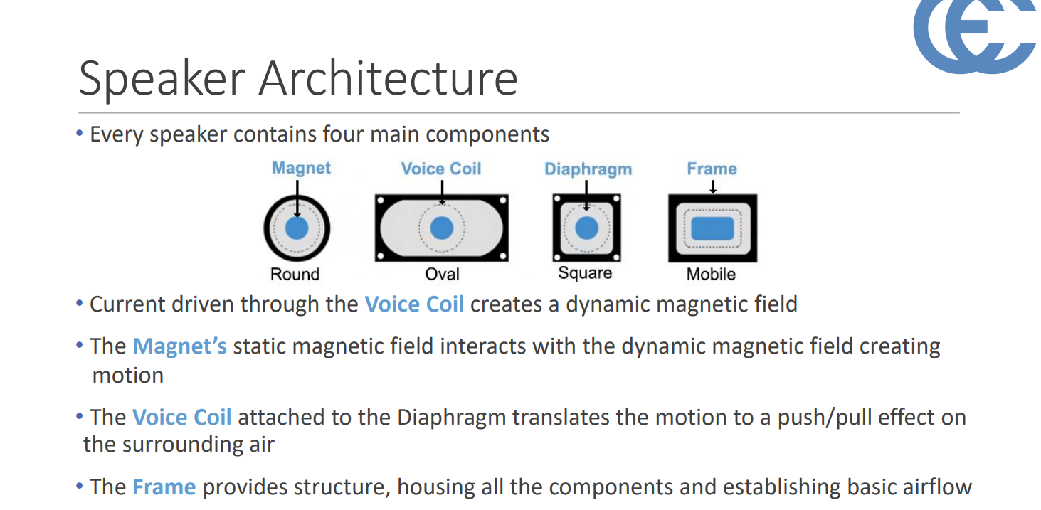
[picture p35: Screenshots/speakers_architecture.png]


So apparently, we'd just have to stick with the old way. Connecting my speakers via a JST connector.

Also begs another question:
- How do i plan to wire the PAM8403 if I'm only using one speaker for one audio module? What about the OUT_R and OUT_L 

Better idea instead of creating a new file:

export a file first with one side of the speaker

and then afterwards we can make changes to the schematic and then do it for the other side of the ear.

So here's the final schematic of the audio schematic. Not much changes were made! Just wanted this to be sanity checked by Gemini.

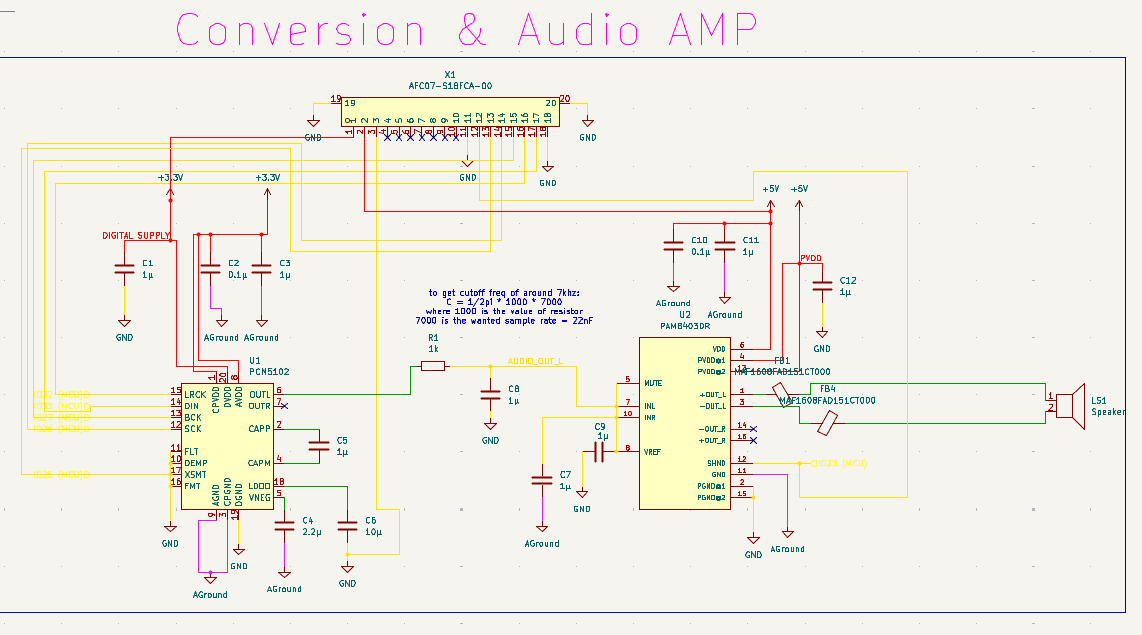
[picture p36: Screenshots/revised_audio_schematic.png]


Okay next thing that popped into my head:
- DGND vs AGND

So connecting to the DGND are for if you have noisy components such as
and then AGND is the quiet part of the schematic in which you will connect components that are susceptible to a lot of noise, and a lot of noise makes the electrical connections inconsistent.

But yeah, I'll be doing that star grounding in the PCB itself. Hopefully I don't forget.

But anyways, that's pretty much it for this.

# Entry 11 - 06-19-26 - Making the PCBs for all the modules

Okay so for this session, I tried brainstorming for a great shape for the PCB of each module. Turns out, if I want to make this be mounted on a pod, I'd have to just make it into a simple chamferred rectangle shape.

Yep! Now, getting back to the routing. Here's the final routed pcb:

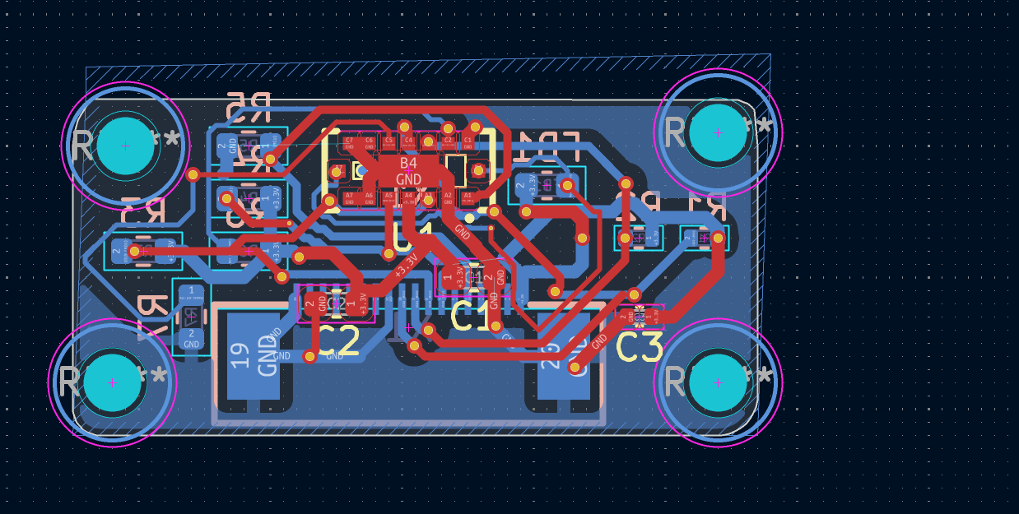
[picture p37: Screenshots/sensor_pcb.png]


Sensor PCB! (Will add mounting holes)

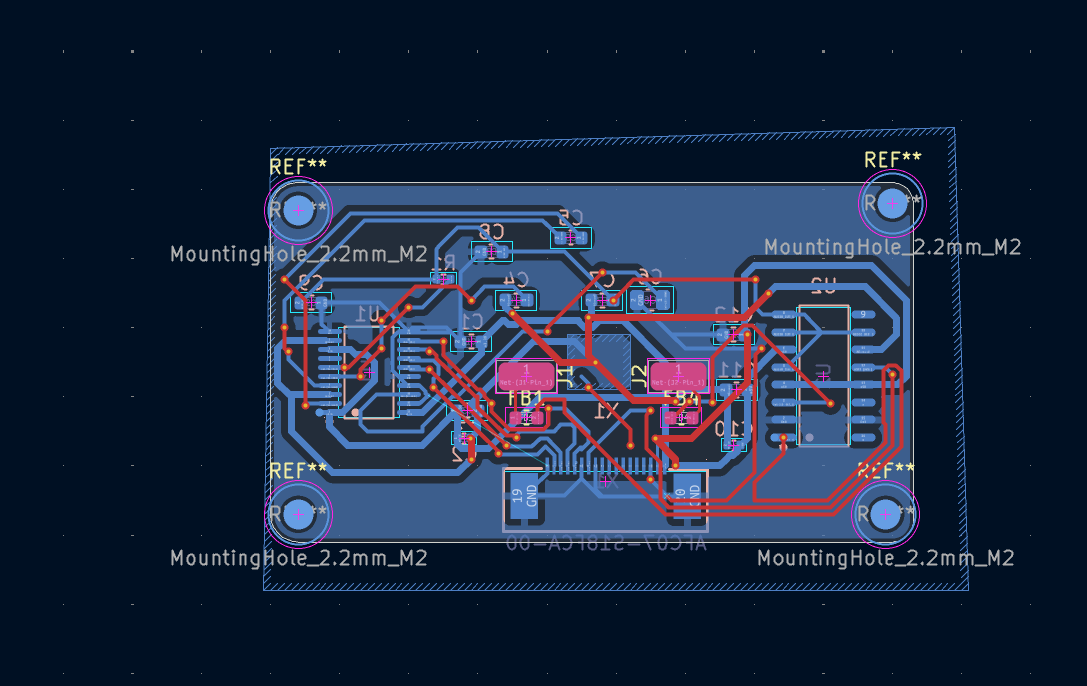
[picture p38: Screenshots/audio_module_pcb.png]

Audio PCB!

Also adding mounting holes for M2 screws in the PCB so we can attach it in the 3d model im going to do (the said pods)

Okay so now for the main pcb.

Let's make the chip to the front
make the fpcs to the front?
power stuff, at the back

I actually forgot to add the pogo pins for programming the system. Actually no we don't need that hahahhaa.
I'll just get a programming pogo pin testing jig so I can program it without having any permanent obstructions in the pcb.

Here's how it looks like right now:

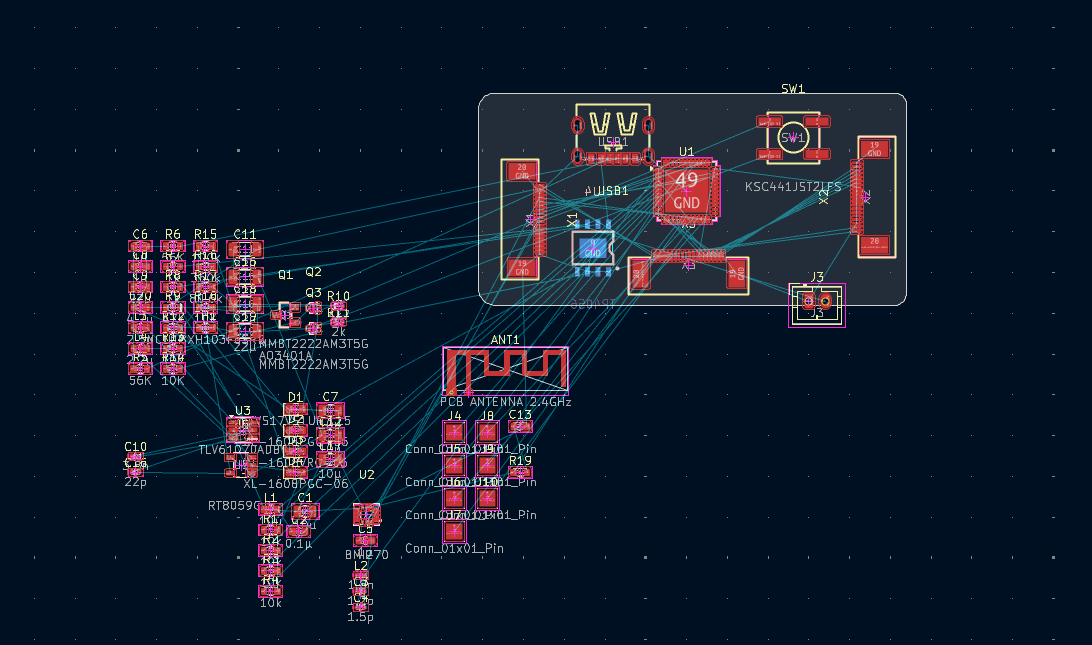
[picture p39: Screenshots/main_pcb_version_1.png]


Should be finished tomorrow with the 3D Model design!

# Entry 12 - 06-20-26 - Making the PCBs for all the modules

Well yeah, as the journal title said, It's literally just mostly me routing. You can see the timelapse.

Also decided on the orientation of this to be vertical:

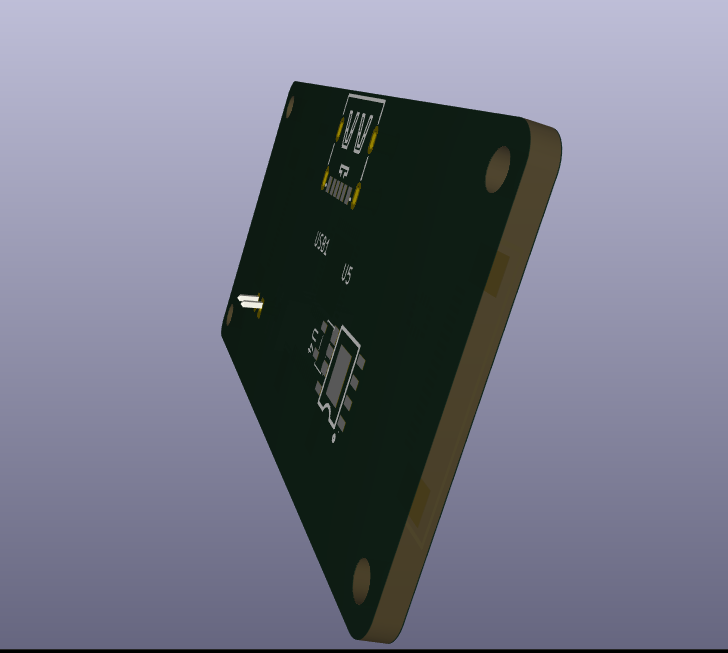
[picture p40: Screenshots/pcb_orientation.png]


Also caught this being two NPN transistors when its should be a NPN and a PNP transistor

The PNP transistor is the main switch for making the power flood in
The NPN transistor reaches out and then pulls down the handle to unlock the door.

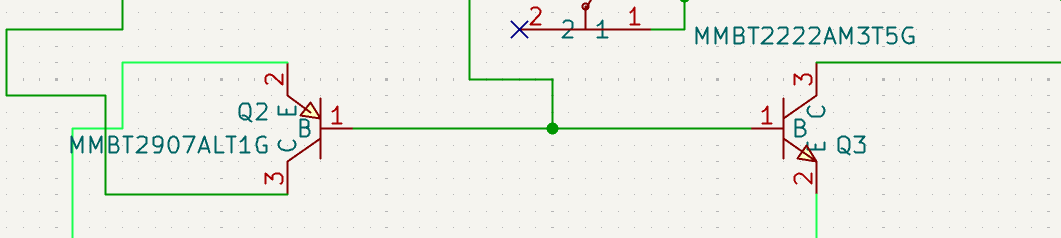
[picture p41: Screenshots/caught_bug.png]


Here's the main pcb:

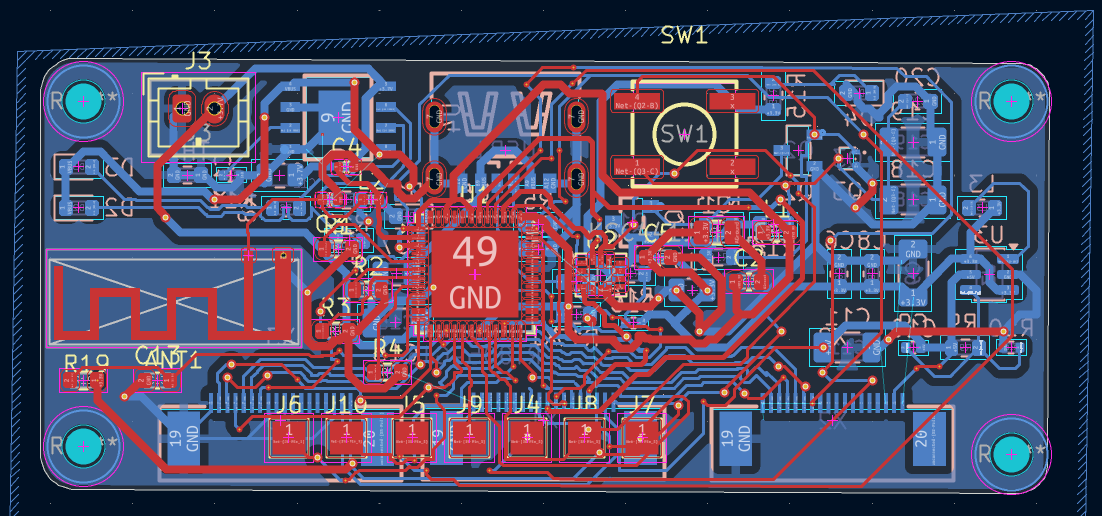
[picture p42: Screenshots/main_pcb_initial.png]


Routing WAS VERY tough with this one

# Entry 13 - 06-21-26 - Making the CAD for the design
Okay next would be the 3D model design...

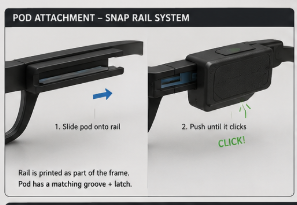
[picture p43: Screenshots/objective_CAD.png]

I want to replicate something like this. Not sure how but I'll make it work.

Making pod number 1!
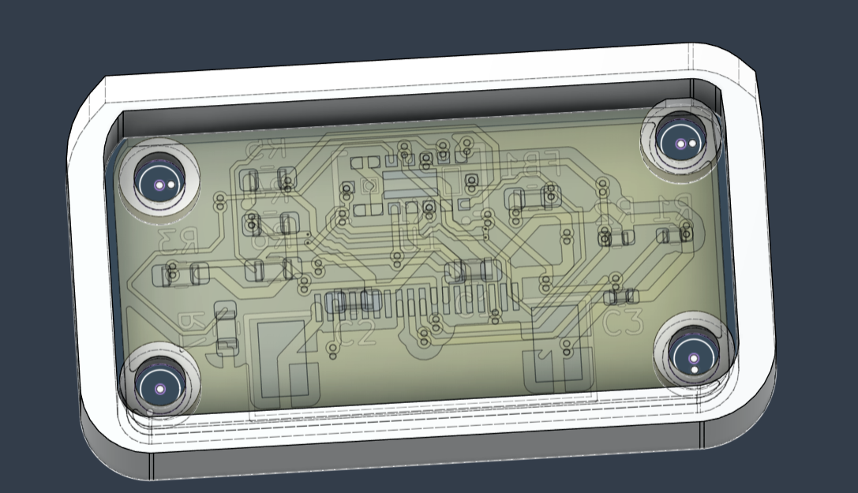
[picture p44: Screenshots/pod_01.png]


it's surprisingly easy. You just have to really do offset and then put in the standoffs.

I haven't combined it yet

Next would be the temples of the glasses. You just create a 95 mm line to the right and then make a 45 degree angled line. Replace that line with a 3 point fix-point spline. Combine both and extrude!!

Now go to the top-bottom view and create a three point spline that encomapsses the entire thing. Extrude then intersect it with the blocky temple to make it have a smooth look!

Okay I will also be modifying the glasses temple to be according to a FPC cable 

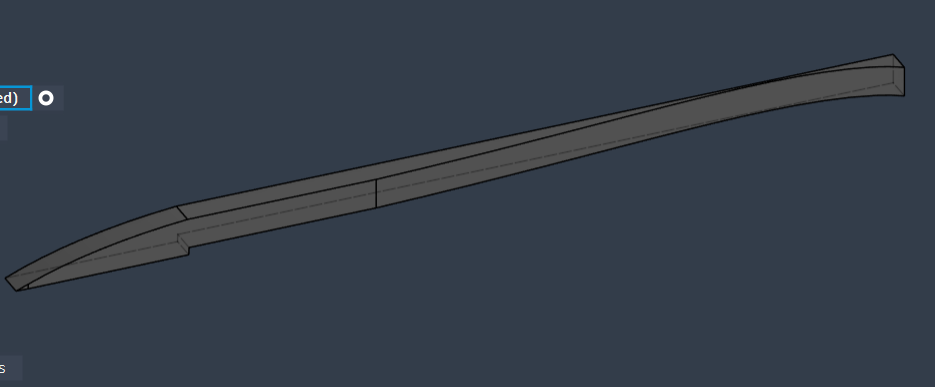
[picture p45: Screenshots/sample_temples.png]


Here's how the temples will be like. Will add snap rail thing.

Oh yeah, apparently, that type of mechanism is called a sliding dove tail. I simply just used the flat side of the templse and then created some sort of rail with an extrusion of 1.2mm

Then after that, I went and refined ALOT of stuff. I didn't have time to journal. But after this, it is most likely the files you see now.

Yeah honestly, in the end I decided to just end it there for now.

HAD A FRIEND check it but fallout submissions are gonna be due TT.
# Entry 14 - 06-21-26 - Making the zine + submitting requirements

Yep! Exactly what the title of the journal is.
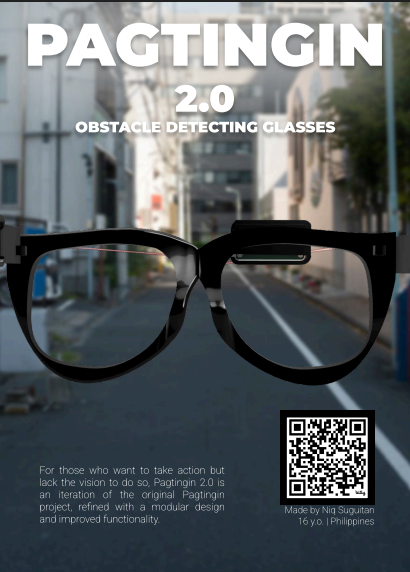
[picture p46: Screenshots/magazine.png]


# Entry 15 - 06-24-26 - Making the steps of my project + resubmitting

Yeah so for this I recently had my project returned so now I'm going to comply with them.

Also added some steps on how to replicate this project in the README!

I also made this new zine!! :D



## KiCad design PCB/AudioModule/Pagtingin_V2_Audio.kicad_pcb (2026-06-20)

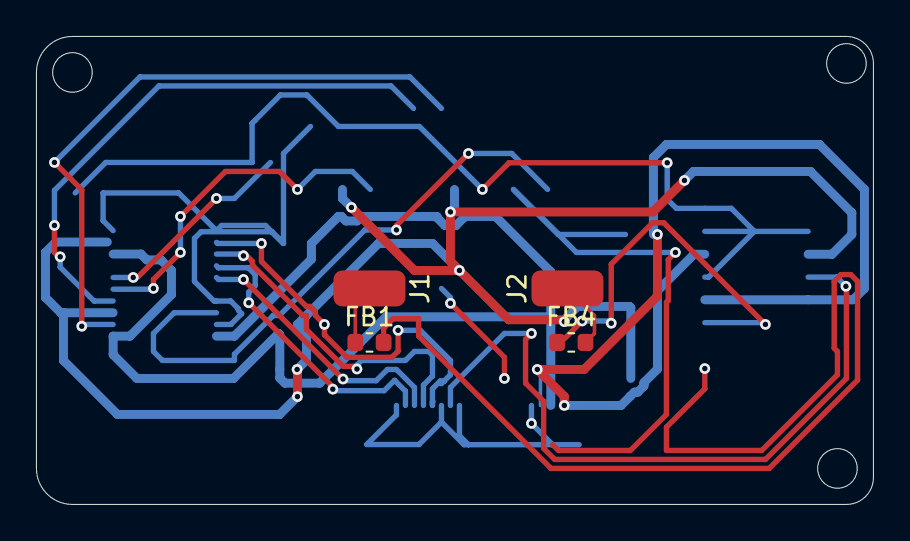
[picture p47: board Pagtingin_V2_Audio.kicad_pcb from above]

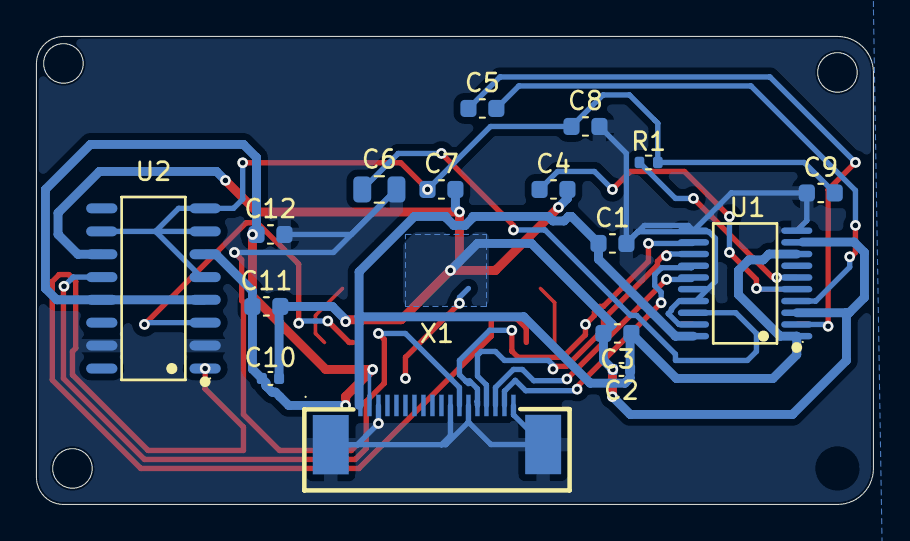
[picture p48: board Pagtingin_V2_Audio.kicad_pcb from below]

Board: 2 copper layers, 46.5 x 26.0 mm, 20 parts (16 on the bottom side), 19 nets.

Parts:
C1, C3, C5, C7, C8, C9, C11, C12: 1µ; C_0603_1608Metric
C2, C10: 0.1µ; C_0402_1005Metric
C4: 2.2µ; C_0603_1608Metric
C6: 10µ; C_0805_2012Metric
FB1, FB4: MAF1608FAD151CT000; L_0603_1608Metric
J1, J2: Conn_01x01_Pin; SolderWirePad_1x01_SMD_2x4mm
R1: 1k; R_0402_1005Metric
U1: PCM5102; TSSOP-20_L6.5-W4.4-P0.65-LS6.4-BL
U2: PAM8403DR; SOP-16_L10.0-W3.9-P1.27-LS6.0-BL
X1: AFC07-S18FCA-00; FPC-SMD_AFC07-S18FCA-00

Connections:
+3.3V: C1.1, C2.1, C3.1, U1.1 (CPVDD), U1.8 (AVDD), U1.20 (DVDD), X1.1
+5V: C10.1, C11.1, C12.1, U2.4 (PVDD@1), U2.6 (VDD), U2.13 (PVDD@2), X1.2
/AUDIO_OUT_L: C7.1, C8.1, C9.2, R1.2, U2.5 (MUTE), U2.7 (INL), U2.8 (VREF), U2.10 (INR)
/IO23 (MCU): U2.12 (SHND), X1.12
/IO26 (MCU): U1.12 (SCK), X1.14
/IO27 (MCU): U1.13 (BCK), X1.15
/IO32 (MCU): U1.15 (LRCK), X1.16
/IO33 (MCU): U1.14 (DIN), X1.17
AGround: C2.2, C3.2, C4.2, C7.2, C10.2, C11.2, U1.3 (CPGND), U1.9 (AGND), U2.11 (GND)
GND: C1.2, C6.2, C8.2, C9.1, C12.2, U1.10 (DEMP), U1.11 (FLT), U1.16 (FMT), U1.17 (XSMT), U1.19 (DGND), U2.2 (PGND@1), U2.15 (PGND@2), X1.3, X1.11, X1.13, X1.18, X1.19, X1.20
unnamed: FB1.1, J1.1 (Pin_1_1)
unnamed: FB4.2, J2.1 (Pin_1_1)
unnamed: C5.2, U1.4 (CAPM)
unnamed: C5.1, U1.2 (CAPP)
unnamed: C6.1, U1.18 (LDOO)
unnamed: R1.1, U1.6 (OUTL)
unnamed: C4.1, U1.5 (VNEG)
unnamed: FB1.2, U2.1 (+OUT_L)
unnamed: FB4.1, U2.3 (-OUT_L)

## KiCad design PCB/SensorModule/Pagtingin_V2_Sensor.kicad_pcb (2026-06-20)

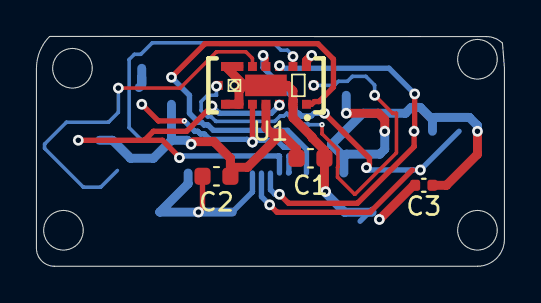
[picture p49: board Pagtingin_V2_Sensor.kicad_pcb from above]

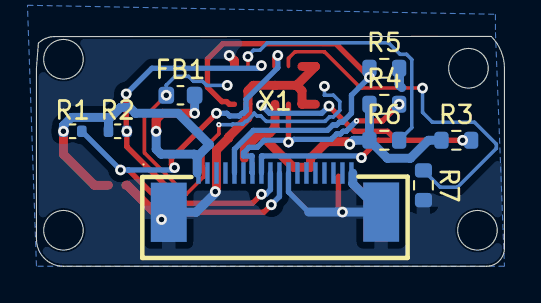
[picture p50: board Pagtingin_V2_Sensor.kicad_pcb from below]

Board: 2 copper layers, 26.0 x 12.8 mm, 13 parts (9 on the bottom side), 10 nets.

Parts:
C1, C2: 1µ; C_0603_1608Metric
C3: 0.1µ; C_0402_1005Metric
FB1: MAF1608FAD151CT000; L_0603_1608Metric
R1, R2: 2k2; R_0402_1005Metric
R3, R4, R5, R6: 47k; R_0603_1608Metric
R7: 10k; R_0603_1608Metric
U1: VL53L5CXV0GC_1; LGA-16_L6.4-W3.0_VL53L5CXV0GC-1
X1: AFC07-S18FCA-00; FPC-SMD_AFC07-S18FCA-00

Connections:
+3.3V: C1.1, C2.1, C3.1, FB1.2, R1.1, R2.1, R3.1, R4.1, R6.1, U1.A4 (IOVDD), X1.1
/IO4 (MCU): R5.1, U1.A1 (I2C_RST), X1.5
/IO18 (MCU): R4.2, U1.A5 (LPN), X1.7
/IO19 (MCU): R3.2, U1.A3 (INT), X1.8
/IO21 (MCU): R2.2, U1.C3 (SDA), X1.9
/IO22 (MCU): R1.2, U1.C4 (SCL), X1.10
GND: C1.2, C2.2, C3.2, R5.2, R7.2, U1.A2 (RSVD4), U1.A6 (RSVD1), U1.A7 (RSVD2), U1.B4 (THERMALPAD), U1.C1 (GND), U1.C6 (RSVD3), U1.C7 (GND), X1.3, X1.11, X1.18, X1.19, X1.20
unnamed: FB1.1, U1.B1 (AVDD), U1.B7 (AVDD)
unnamed: R7.1, U1.C5 (RSVD5)
unnamed: R6.2, U1.C2 (RSVD6)

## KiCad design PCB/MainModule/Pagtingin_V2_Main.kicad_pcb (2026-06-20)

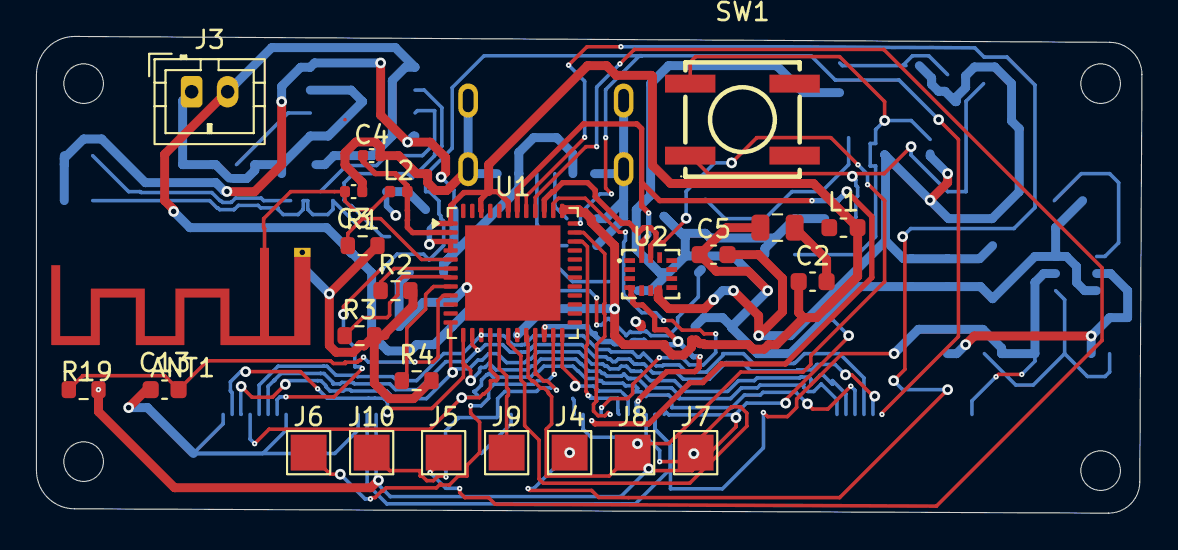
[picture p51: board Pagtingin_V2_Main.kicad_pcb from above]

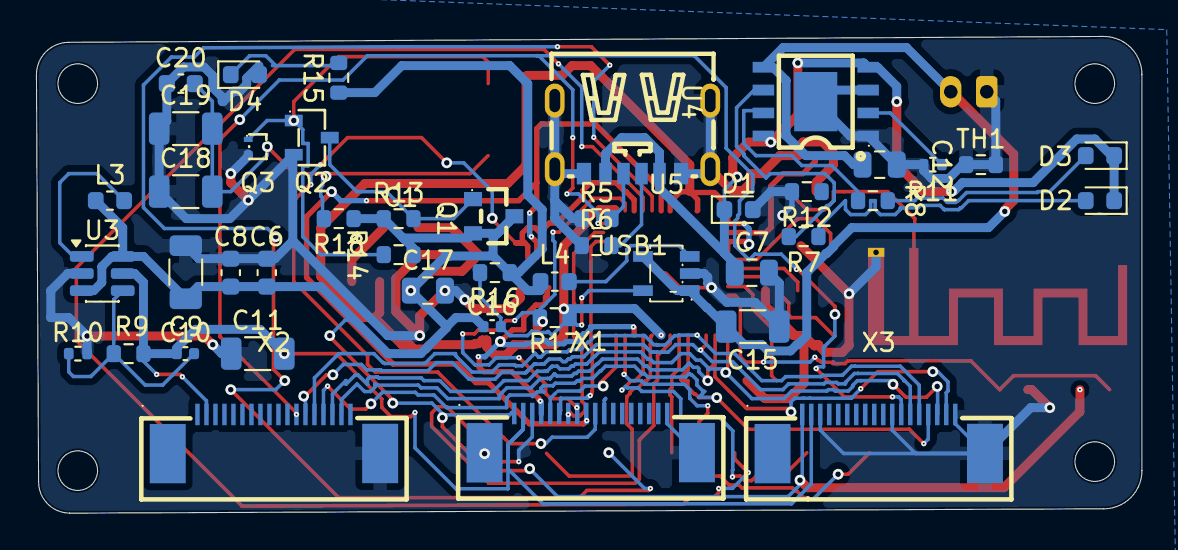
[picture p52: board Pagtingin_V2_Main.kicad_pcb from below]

Board: 2 copper layers, 61.4 x 26.5 mm, 69 parts (44 on the bottom side), 49 nets.

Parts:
ANT1: PCB ANTENNA 2.4GHz; Texas_SWRA117D_2.4GHz_Right
C1, C7, C12, C17: 10µ; C_0805_2012Metric
C2, C13: 0.1µ; C_0603_1608Metric
C3: 1.2p; C_0402_1005Metric
C4: 1.5p; C_0402_1005Metric
C5, C6, C8: 1µ; C_0603_1608Metric
C9: 22µ; C_1206_3216Metric
C10: 3.8n; C_0402_1005Metric
C11, C15, C18, C19: 22μ; C_1206_3216Metric
C16: 22p; C_0402_1005Metric
C20: 4.7μ; C_0603_1608Metric
D1: PTVS17VS1UR,115; D_0603_1608Metric
D2, D4: XL-1608PGC-06; LED_0603_1608Metric
D3: XL-1608VRC-06; LED_0603_1608Metric
J3: USE-702528-500PCBJST; JST_PH_B2B-PH-K_1x02_P2.00mm_Vertical
J4, J5, J6, J7, J8, J9, J10: Conn_01x01_Pin; TestPoint_Pad_2.0x2.0mm
L1: 10µ; L_0603_1608Metric
L2: 1.8n; L_0402_1005Metric
L3: 2.5µ; L_0603_1608Metric
L4: 2.2µ; L_0603_1608Metric
Q1: AO3401A; SOT-23_L2.9-W1.3-P1.90-LS2.4-BR
Q2: MMBT2907ALT1G; SOT-23-3_L2.9-W1.3-P1.90-LS2.4-BR
Q3: MMBT2222AM3T5G; SOT-723-3_L1.2-W0.8-P0.80-LS1.2-BR
R1, R2, R3, R4, R12, R19: 10k; R_0603_1608Metric
R5, R6: 56K; R_0603_1608Metric
R7, R8: 1k; R_0603_1608Metric
R9: 47k; R_0603_1608Metric
R10: 4k7; R_0402_1005Metric
R11: 2k; R_0402_1005Metric
R13, R14, R18: 10K; R_0603_1608Metric
R15: 100k; R_0603_1608Metric
R16: 360k; R_0603_1608Metric
R17: 80.6k; R_0603_1608Metric
SW1: KSC441JST2LFS; KEY-SMD_4P-L6.2-W6.2-P4.00-LS6.8
TH1: NCU18XH103F6SRB; R_0603_1608Metric
U1: ESP32-PICO-D4; QFN-48-1EP_7x7mm_P0.5mm_EP5.3x5.3mm
U2: BMI270; LGA-14_L3.0-W2.5-P0.50-BR
U3: TLV61070ADBV; SOT-23-6
U4: TP4056; ESOP-8_L4.9-W3.9-P1.27-LS6.0-BL-EP
U5: RT8059GJ5; SOT-23-5_L3.0-W1.7-P0.95-LS2.8-BR
USB1: TYPE-C 6P; TYPE-C-SMD_TYPE-C-6P_1
X1, X2, X3: AFC07-S18FCA-00; FPC-SMD_AFC07-S18FCA-00

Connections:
+3.3V: C1.1, C5.1, C6.1, C8.1, C9.1, C16.1, C17.1, L1.1, L3.1, L4.2, Q1.2 (S), Q1.3 (D), R13.1, R14.1, R15.1, R16.1, R18.1, R19.1, U2.5 (VDDIO), U2.8 (VDD), U2.12 (CSB), U3.3 (EN), U3.6 (V_{IN}), X1.1, X2.1, X3.1
+3.7V: C12.1, C15.2, J3.2, U4.5 (BAT), U5.1 (EN), U5.4 (VIN)
/+3V3_RF: C2.1, L1.2, U1.1 (VDDA), U1.3 (VDDA3P3), U1.4 (VDDA3P3), U1.19 (VDD3P3_RTC), U1.37 (VDD3P3_CPU), U1.43 (VDDA), U1.46 (VDDA)
/IMU/IO2 (MCU): U1.22 (IO2), U2.4 (INT1), X1.4
/IMU/IO21 (MCU): U1.42 (IO21), U2.14 (SDX), X1.9
/IMU/IO22 (MCU): U1.39 (IO22), U2.13 (SCX), X1.10
/Power System/+5V: C10.1, C11.2, R9.1, U3.5 (V_{OUT}), X1.2, X2.2, X3.2
/Power System/VBUS: C7.1, D1.1 (K), D2.1 (K), D3.1 (K), R12.1, U4.4 (VCC), U4.8 (CE), USB1.A9 (VBUS), USB1.B9 (VBUS)
/Programmer/LNA_IN (MCU): C4.1, L2.2, U1.2 (LNA_IN)
AGround: C1.2, C2.2
GND: ANT1.2, C3.2, C4.2, C5.2, C6.2, C7.2, C8.2, C9.2, C11.1, C12.2, C13.2, C15.1, C17.2, C18.1, C19.1, C20.1, D1.2 (A), D4.2 (A), J3.1, Q2.2 (E), Q3.2 (E), R1.2, R2.2, R3.2, R4.2, R5.1, R6.1, R10.2, R11.1, R12.2, R17.2, TH1.1, TH1.2, U1.49 (GND), U2.6 (GNDIO), U2.7 (GND), U3.2 (GND), U4.1 (TEMP), U4.3 (GND), U4.9 (EP), U5.2 (GND), USB1.7 (EH), USB1.A12 (GND), USB1.B12 (GND), X1.3, X1.11, X1.18, X1.19, X1.20, X2.3, X2.11, X2.18, X2.19, X3.3, X3.11, X3.18, X3.19
unnamed: ANT1.1, C3.1, L2.1
unnamed: D2.2 (A), R7.1
unnamed: D3.2 (A), R8.1
unnamed: D4.1 (K), R15.2
unnamed: J4.1 (Pin_1_1), U1.41 (U0TXD/IO1)
unnamed: J5.1 (Pin_1_1), U1.40 (U0RXD/IO3)
unnamed: J6.1 (Pin_1_1), U1.23 (IO0)
unnamed: J7.1 (Pin_1_1), U1.18 (IO12)
unnamed: J8.1 (Pin_1_1), U1.20 (IO13)
unnamed: J9.1 (Pin_1_1), U1.17 (IO14)
unnamed: J10.1 (Pin_1_1), U1.21 (IO15)
unnamed: Q1.1 (G), Q2.3 (C), R13.2
unnamed: Q2.1 (B), Q3.1 (B), R14.2, SW1.4
unnamed: C18.2, C19.2, C20.2, Q3.3 (C), R18.2, SW1.1
unnamed: C13.1, R19.2, U1.9 (EN)
unnamed: U1.24 (IO4), X1.5
unnamed: U1.34 (IO5), X1.6
unnamed: U1.35 (IO18), X1.7
unnamed: U1.38 (IO19), X1.8
unnamed: U1.36 (IO23), X2.12, X3.12
unnamed: U1.14 (IO25), X2.13, X3.13
unnamed: U1.15 (IO26), X2.14, X3.14
unnamed: U1.16 (IO27), X2.15, X3.15
unnamed: U1.12 (IO32), X2.16, X3.16
unnamed: U1.13 (IO33), X2.17, X3.17
unnamed: R3.1, U1.7 (SENSOR_CAPN)
unnamed: R2.1, U1.6 (SENSOR_CAPP)
unnamed: R4.1, U1.8 (SENSOR_VN)
unnamed: R1.1, U1.5 (SENSOR_VP)
unnamed: L3.2, U3.1 (SW)
unnamed: C10.2, R9.2, R10.1, U3.4 (V_{FB})
unnamed: R11.2, U4.2 (PROG)
unnamed: R8.2, U4.7 (~CHRG)
unnamed: R7.2, U4.6 (~STDBY)
unnamed: C16.2, R16.2, R17.1, U5.5 (FB)
unnamed: L4.1, U5.3 (LLX)
unnamed: R6.2, USB1.A5 (CC1)
unnamed: R5.2, USB1.B5 (CC2)

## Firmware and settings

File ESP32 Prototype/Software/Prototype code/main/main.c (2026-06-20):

#include "main.h"

//Move between states
void idle_state() {
    esp_wifi_stop();

    should_measure = true;
    should_read = true;
    
    vTaskDelay(pdMS_TO_TICKS(100));

    if (distance_cm <= 50) {
        current_state = STATE_ALERT;
    }
    else {
        current_state = STATE_IDLE;
    }
}

void alert_state() {
    //Handle alert behavior
    should_output = true;

    //Revert back to original state
    vTaskDelay(pdMS_TO_TICKS(100));
    current_state = STATE_MUTE;
}

void mute_state() {
    //Mute behavior: Shutdown all active tasks

    if (write_handler)  {
        vTaskDelete(write_handler);
        write_handler = NULL;
    }

    if (read_handler) {
        vTaskDelete(read_handler);
        read_handler = NULL;
    }

    if (music_handler) {
        vTaskDelete(music_handler);
        music_handler = NULL;
    }

    vTaskDelay(pdMS_TO_TICKS(100));
    //Re loop
    current_state = STATE_IDLE;
}

void gpio_init(void) {
     // GPIO PINS
     gpio_config_t io_configurations = {};

     // OUTPUT:
     io_configurations.intr_type = GPIO_INTR_DISABLE; 
     io_configurations.pin_bit_mask = GPIO_OUTPUT_PIN_SEL;
     io_configurations.mode = GPIO_MODE_OUTPUT;
     io_configurations.pull_down_en = 0;
     io_configurations.pull_up_en = 0;
 
     ret = gpio_config(&io_configurations);
     if (ret == ESP_OK) {
        ESP_LOGI(TAG, "GPIO Output Initiated\n");
     }
 
     // INPUT:
     io_configurations.intr_type = GPIO_INTR_DISABLE;
     io_configurations.pin_bit_mask = GPIO_INPUT_PIN_SEL;
     io_configurations.mode = GPIO_MODE_INPUT;
     io_configurations.pull_down_en = 0;
     io_configurations.pull_up_en = 0;
 
     ret = gpio_config(&io_configurations);
     if (ret == ESP_OK) {
         ESP_LOGI(TAG, "GPIO Input Initiated\n");

     }
 }

void uart_init() {
    TAG = "UART";
    // UART Configuration
    uart_config_t uart_config = {
        .baud_rate = 115200,
        .data_bits = UART_DATA_8_BITS,
        .parity = UART_PARITY_DISABLE,
        .stop_bits = UART_STOP_BITS_1,
        .flow_ctrl = UART_HW_FLOWCTRL_DISABLE,
        .source_clk = UART_SCLK_DEFAULT,
    };
    
    uart_param_config(uart_port_num, &uart_config);
    if ((ret = uart_set_pin(uart_port_num, UART_TX_PIN, UART_RX_PIN, UART_PIN_NO_CHANGE, UART_PIN_NO_CHANGE)) != ESP_OK) {
        ESP_LOGE(TAG, "Error occured: %s\n", esp_err_to_name(ret));
    }
    
    if ((ret = uart_set_pin(uart_port_num, UART_TX_PIN, UART_RX_PIN, UART_PIN_NO_CHANGE, UART_PIN_NO_CHANGE)) != ESP_OK) {
        ESP_LOGE(TAG, "Error occured: %s\n", esp_err_to_name(ret));
    }
}

void i2c_reset() {
    gpio_set_level(GPIO_OUTPUT_IO_4, 0);
    gpio_set_level(GPIO_OUTPUT_IO_5, 0);
    vTaskDelay(pdMS_TO_TICKS(100));
    gpio_set_level(GPIO_OUTPUT_IO_4, 1);
    gpio_set_level(GPIO_OUTPUT_IO_5, 0);
    vTaskDelay(pdMS_TO_TICKS(100));
    gpio_set_level(GPIO_OUTPUT_IO_4, 0);
    gpio_set_level(GPIO_OUTPUT_IO_5, 0);
    vTaskDelay(pdMS_TO_TICKS(100));
}
  
 void i2c_init() {
    i2c_reset();
    TAG = "I2C";
    //The bus handle is like a USB hub maanger,
    //all configurations are plugged into this hub
        //Set GPIO 02 to make I2C comms of the sensor enabled
    gpio_set_level(GPIO_OUTPUT_IO_2, 0);
    gpio_set_level(GPIO_OUTPUT_IO_18, 0);

    vTaskDelay(pdMS_TO_TICKS(100));
    
    /* TOF SENSOR 01 */
    gpio_set_level(GPIO_OUTPUT_IO_2, 1);
    vTaskDelay(pdMS_TO_TICKS(100));

    i2c_master_bus_handle_t tof_bus_handle_0;
    
    //Handler for the specific I2C device (usually a slave) on the I2C bus
    i2c_master_dev_handle_t tof_dev_handle_0;    

    // I2C  master configuration (ESP32)
    i2c_master_bus_config_t tof_mst_config_0 = {
        .clk_source = I2C_CLK_SRC_DEFAULT,
        .i2c_port = I2C_PORT_NUM_0,
        .scl_io_num = I2C_MASTER_SCL_IO,
        .sda_io_num = I2C_MASTER_SDA_IO,
        .glitch_ignore_cnt = 7,
        .flags.enable_internal_pullup = true,
    };

    //Used for debugging
    ret = i2c_new_master_bus(&tof_mst_config_0, &tof_bus_handle_0);
    if (ret != ESP_OK) {
        ESP_LOGE(TAG, "I2C Master Bus 0 did not activate! Error: %s\n", esp_err_to_name(ret));
    }
    
    i2c_device_config_t tof_dev_config_0 = {
        //Configure the slave's parameters to distinguish identity
        .dev_addr_length = I2C_ADDR_BIT_LEN_7,
        .device_address = I2C_TOF_DEFAULT_ADDRESS,
        .scl_speed_hz = 100000,
    };

    ret = i2c_master_bus_add_device(tof_bus_handle_0, &tof_dev_config_0, &tof_dev_handle_0);
    if (ret != ESP_OK) {
        ESP_LOGE(TAG, "TOF 0 Error: %s\n", esp_err_to_name(ret));
    }

    uint8_t change_address_cmd1[2] = {0x8A, I2C_TOF1_ADDRESS & 0X7F};
    i2c_master_transmit(tof_dev_handle_0, change_address_cmd1, 2, 1000);

     /* TOF SENSOR 02 */

    i2c_master_dev_handle_t tof_dev_handle_1;
    gpio_set_level(GPIO_OUTPUT_IO_18, 1);
    vTaskDelay(pdMS_TO_TICKS(100));

    i2c_device_config_t tof_dev_config_1 = {
        //Configure the slave's parameters to distinguish identity
        .dev_addr_length = I2C_ADDR_BIT_LEN_7,
        .device_address = I2C_TOF_DEFAULT_ADDRESS,
        .scl_speed_hz = 100000,
    };


    ret = i2c_master_bus_add_device(tof_bus_handle_0, &tof_dev_config_1, &tof_dev_handle_1);
    if (ret != ESP_OK) {
        ESP_LOGE(TAG, "TOF 1 Error: %s\n", esp_err_to_name(ret));
    }

    uint8_t change_address_cmd2[2] = {0x8A, I2C_TOF2_ADDRESS & 0X7F};
    i2c_master_transmit(tof_dev_handle_0, change_address_cmd2, 2, 1000);
}

void write_to_tof(void *pvParameters) {
    if (should_measure == true) {
        printf("Taking measurements...");
        TAG = "I2C";
        /* Main Purpose: Writing to turn on and off (loop this function) */ 
        static uint8_t write_buffer[2];
        write_buffer[0] = 0x00;
        //Start a single measurement
        write_buffer[1] = 0x01;

        ret = i2c_master_transmit(i2c_dev, (uint8_t *)write_buffer, 2, 1000);
        if (ret != ESP_OK) {
            ESP_LOGE(TAG, "Slave could not receive data. Error: %s\n", esp_err_to_name(ret));
        }
        else {
            ESP_LOGI(TAG, "Slave received data");
    }

    vTaskDelay(pdMS_TO_TICKS(100));
    }
}

void read_from_tof(void *pvParameters) {
    if (should_read == true) {
        printf("Reading measurements...");
        TAG = "I2C";
        /* Main Purpose: Converting and getting distance measurements */
        
        //Register for getting result of the sensor
        uint8_t read_buffer;

        //Keep looping until the the last three bits become 1
        while ((read_buffer & 0x07) == 0) {
            uint8_t reg_addr = 0x13;
                
            i2c_master_transmit(i2c_dev, &reg_addr, 1, 1000);

            i2c_master_receive(i2c_dev, &read_buffer, 1, 1000);
        }

        //Once the bits become 1, we want to get that measurement (read)
        uint8_t reg_addr = 0x1E;
        uint8_t raw_distance[2];

        i2c_master_transmit(i2c_dev, &reg_addr, 1, 1000);
        i2c_master_receive(i2c_dev, raw_distance, 2, 1000);

        //Convert to the distance to cm
        uint16_t distance_mm = (raw_distance[0] << 8) | raw_distance[1];
        distance_cm = distance_mm / 10;
        ESP_LOGI(TAG, "Distance: %dcm", distance_cm);
    }
}


esp_err_t i2s_init() {
    TAG = "I2S";
    
    //READY PHASE

    //I2S struct for initializing
    i2s_chan_config_t i2s_channel_cfg = I2S_CHANNEL_DEFAULT_CONFIG(I2S_NUM_0, I2S_ROLE_MASTER);
    //Allow for tx handler only since we're only transmitting audio data
    ESP_ERROR_CHECK(i2s_new_channel(&i2s_channel_cfg, &tx_handler, NULL));
    
    i2s_std_config_t i2s_cfg = {
        .slot_cfg = I2S_STD_PHILIPS_SLOT_DEFAULT_CONFIG(I2S_DATA_BIT_WIDTH_16BIT , I2S_SLOT_MODE_STEREO),
        .clk_cfg = I2S_STD_CLK_DEFAULT_CONFIG(SAMPLE_RATE),
        .gpio_cfg = {
            .mclk = SCK_IO,
            .bclk = BCK_IO,
            .ws = LRCK_IO,
            .dout = DOUT_IO,
            .din = I2S_GPIO_UNUSED,
            .invert_flags = {
                .mclk_inv = false,
                .bclk_inv = false,
                .ws_inv = false,
            },
        },
    };


    //REGISTERED PHASE
    ESP_ERROR_CHECK(i2s_channel_init_std_mode(tx_handler, &i2s_cfg));
    ESP_ERROR_CHECK(i2s_channel_enable(tx_handler));
    
    gpio_set_level(GPIO_OUTPUT_IO_25, 1);
    gpio_set_level(GPIO_OUTPUT_IO_23, 1);

    return ESP_OK;
}

int map(int distance, int starting_low, int starting_high, int ending_low, int ending_high) {
    return (distance - starting_low) * (ending_high - ending_low) / (starting_high - starting_low) + ending_low;
}


static void i2s_write_beeps() {
    if (should_output == true) {
        printf("Outputting sound...");
        /* Write bytes in order to sound beeps*/
        TAG = "I2S";

        //Buffer for storing samples
        size_t written_bytes = 0;
        int16_t NUM_SAMPLES = ((int)(SAMPLE_RATE * DURATION));

        //Stereo buffer for storing samples
        int16_t *stereo_buf = malloc(NUM_SAMPLES * 2 * sizeof(int16_t));

        int16_t *silent_buf = malloc(NUM_SAMPLES * 2 * sizeof(int16_t));
        
        int samples_a_cycle = SAMPLE_RATE / BEEP_FREQ;
            
        /*Since we're making a square wave for a harsh buffer sound,
        we would need to alternate between the highest and lowest amplitude
        */
        for (int i = 0; i < NUM_SAMPLES; i++)  {
            int amplitude = ((int)(i / samples_a_cycle) % 2 == 0) ? 30000: -30000;

            stereo_buf[2 * i] = amplitude;
            stereo_buf[2 * i + 1] = amplitude;

            silent_buf[2 * i] = 0;
            silent_buf[2 * i + 1] = 0;
        }

        buzz_flag = true;

        if (buzz_flag == true) {
        //Write to existing channel
        beep_delay = map(distance_cm, 0, THRESHOLD, BUZZER_MIN, BUZZER_MAX);
        ESP_ERROR_CHECK(i2s_channel_write(tx_handler, stereo_buf, NUM_SAMPLES * 2 * sizeof(int16_t), &written_bytes, 1000));
        vTaskDelay(pdMS_TO_TICKS(beep_delay));
        ESP_ERROR_CHECK(i2s_channel_write(tx_handler, silent_buf, NUM_SAMPLES * 2 * sizeof(int16_t), &written_bytes, 1000));
        vTaskDelay(pdMS_TO_TICKS(beep_delay));

        ESP_LOGI(TAG, "You received a beep!");
        buzz_flag = false;
        }

        free(stereo_buf);
        free(silent_buf);
    }
}

void create_tasks() {
    xTaskCreatePinnedToCore(
            write_to_tof,
            "get_measurement",
            2048,
            NULL,
            1,
            &write_handler,
            1
    );

    xTaskCreatePinnedToCore(
            read_from_tof,
            "read_measurement",
            2048,
            NULL,
            1,
            &read_handler,
            1
        );

        xTaskCreatePinnedToCore(
        i2s_write_beeps,
        "Buzzer_beeps",
        2048,
        NULL,
        1,
        &music_handler,
        1
    );
}

void app_main(void)
{   
    //Initialize the protocols
    gpio_init();
    uart_init();
    i2c_init();
    i2s_init();
    create_tasks();

    while (1) {
        switch(current_state) {
            case STATE_IDLE:
                idle_state();
                break;
            case STATE_ALERT:
                alert_state();
                break;
            case STATE_MUTE:
                mute_state();
                break;    
        }
    }

}

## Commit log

2026-06-20 pagtingin v2 in new repo
    [BMI270.step, BOM.csv, BOM2.csv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]
2026-06-24 got rid of kicad design files from trakcing
    [Pagtingin_V2.kicad_pcb, Pagtingin_V2.kicad_sch]
2026-06-24 added new zine
    [BMI270.step, BOM.csv, BOM2.csv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]
2026-06-24 got rid of some files
    [BMI270.step, Pagtingin_V2.kicad_pcb, Pagtingin_V2.kicad_sch]
2026-06-25 added full assembly f3z
2026-06-26 added hinges to the glasses' temples
    [Glasses Temples.f3d, Glasses_Temples_with_hinges.f3z, Temples Hinges.stl]
